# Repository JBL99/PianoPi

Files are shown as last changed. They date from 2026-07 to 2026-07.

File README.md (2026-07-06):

# PianoPi

PianoPi is a Raspberry Pi 5 MIDI player for a solenoid-driven piano/keyboard rig.
It plays MIDI files through physical solenoids, mirrors notes to an LED strip, can play speaker audio through FluidSynth, and includes a Tkinter control UI plus a local web control page.

## Features

- Tkinter touchscreen-friendly MIDI player
- Physical solenoid playback through PCA9685 boards
- Sustain pedal control through MIDI CC64
- LED strip note mirroring and idle effects
- FluidSynth speaker playback
- Instrument/track mixer
- Keyboard recording support when `real_piano` is false
- Local web control page on port 8000 by default
- CSV play history log

## Hardware this was built for

- Raspberry Pi 5, 64-bit Raspberry Pi OS
- PCA9685 PWM boards for solenoids
- `pi5neo` LED strip control
- FluidSynth with a General MIDI soundfont
- Optional USB MIDI keyboard for keyboard test mode

## Install system packages

```
sudo apt update
sudo apt install -y python3-pip python3-tk fluidsynth fluid-soundfont-gm alsa-utils git
```

For the local web UI and visualizer, you may also want Chromium installed:

```
sudo apt install -y chromium-browser
```

## Install Python dependencies

```
python3 -m pip install -r requirements.txt
```

On the Pi with hardware attached:

```
python3 -m pip install -r requirements-pi.txt
```

## Configure

Copy the example config:

```
cp player_config.example.json player_config.json
```

Edit `player_config.json`:

```json
{
  "midi_dir": "/home/pi5/Desktop/midiMusicFiles",
  "sound_font": "/usr/share/sounds/sf2/FluidR3_GM.sf2",
  "real_piano": false,
  "touchscreen_osk_auto_show": true,
  "web_host": "0.0.0.0",
  "web_port": 8000
}
```

`real_piano` controls which hardware mode/profile is used:

- `false`: keyboard test rig mode, with recording buttons visible
- `true`: real acoustic piano mode

You can also override a few settings with environment variables:

```
PIANOPI_MIDI_DIR=/path/to/midi PIANOPI_WEB_HOST=127.0.0.1 python3 PianoPi.py
```

## Run

```
python3 PianoPi.py
```

## Web control page

By default the web server binds to:

```text
0.0.0.0:8000
```

That means it listens on all network interfaces so another device on the same trusted local network can open:

http://<your-pi-ip>:8000/
```

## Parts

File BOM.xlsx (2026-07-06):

Description | Name | Qty | Cost | Shipping/Tax | Total | Link
JF-1039B Solenoids | Pack of 100: JF-1039B DC 12V 25N 400mA 10mm Push Pull Linear Actuator Electromagnet Solenoid | 1 | $338.01 | $123.00 | $461.01 | https://www.alibaba.com/product-detail/JF-1039B-DC-12V-25N-400mA_1601296981729.html
4K touch screen monitor | WCKUN 4K Portable Touch Monitor, 15.6" inch 3840 * 2160 UHD w/USB-C HDMI Laptop Monitor, 2000:1 100% RGB IPS ，Aluminum Alloy Shell,10-Point Touch，Dual Speaker, HDR, for Home, Work | 1 | $188.99 |  | $188.99 | https://www.amazon.com/dp/B0DP8NKR5W
Plc driver boards, pnp input 3.3 - 5v, pnp output, 16 channel | 4-16CH 3.3V 5V 12V 24V PNP-NPN Digital Logic Converter 5A MOS Solid State Relay PLC Signal Amplifier Board for Motor Relay | 6 | $21.15 |  | $126.90 | https://www.aliexpress.us/item/3256807238669489.html
Raspberry Pi 8gb | Raspberry Pi 5 8GB RAM Board | 1 | $89.99 | $18.73 | $108.72 | https://www.centralcomputer.com/raspberry-pi-5-8gb-ram-board.html
80/20 Aluminum Extrusion 2020 | Pack of 10: Aluminum Profile Extrusion 2020 1220mm 10PCS T Slot Black European Standard Anodized CNC Aluminum Profile 10 Sets connectors 50PCS Nuts 1PC Spanner for DIY 3D Printer | 1 | $83.39 | $0.00 | $83.39 | https://www.amazon.com/dp/B0CCJ7HBX9
Filament | PLA | 1.1kg*10 Rolls / Black*10 | 0.5 | $89.99 | $0.00 | $44.99 | https://jayo3d.com/products/special-offer-jayo-1-1kg-5-10-rolls-collection-pla-pla-matte-high-speed-matte-petg-3d-printing-filament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
Sustain Pedal Solenoid | Heschen Solenoid Electromagnet, HS-1578B, DC12V 20mm Stroke, Force 50N, Push Pull Type, Open Frame, Linear Motion | 1 | $35.99 |  | $35.99 | https://www.amazon.com/dp/B09T35Z4QR
430 Watt computer power supply | CORSAIR CX series CX430 430W ATX12V v2.3 80 PLUS BRONZE Certified Active PFC Power Supply | 1 | $35.99 | $0.00 | $35.99 | Already had from 2015
256gb nvme SSD | OEM Hyn PVC10 256GB M.2 PCI-e GEN 4X4 NVME SSD Internal Solid State Drive 30mm 2230 Form Factor M Key Steam Deck | 1 | $33.99 |  | $33.99 | https://www.amazon.com/dp/B0FNP68QYR
LED RGB addressable light strip | BTF-LIGHTING FCOB COB WS2811(WS2812B) IC RGB 180LED/m 540IC LED Strip DC5V 9.8FT Individual Addressable Flexible High Density Uniform Light Dream Chasing Color 10mm Width(NO Adapter or Controller) | 1 | $32.99 | $0.00 | $32.99 | https://www.amazon.com/dp/B0D62NN4PL
Screw terminal ground bars | 2 Pack: 2x12 Position Terminal Block Distribution Module Breakout Board for AC DC 15 Amp | 3 | $9.99 | $0.00 | $29.97 | https://www.amazon.com/dp/B0GMHB5VTM
T-Track Nuts | T-Track Nuts Kit, M3 M4 M5 M6 2020 3030 Series for Aluminum Extrusion, Hex Socket Bolts & T-Sliding Nuts | 5 | $4.56 |  | $22.80 | https://www.aliexpress.us/item/3256808316984904.html
Screws to attach solenoids to 3D print | 10-200pcs G10.9 Black Carbon Steel DIN7991 Hex Socket Countersunk ISO7380 Round Allen Hexagon Socket Screw M2 M2.5 M3 M4 M5 M6M8 Carbon (DIN7991), M4(50pcs), 8mm | 5 | $4.23 |  | $21.15 | https://www.aliexpress.us/item/3256807130556980.html
Signal wire | 22 AWG Stranded Wire Spool 25ft Each 6 Colors Flexible 22 Gauge Silicone Hook up Wire Kit Electrical Tinned Copper Wire | 1 | $19.99 |  | $19.99 | https://www.amazon.com/dp/B089D29FHC?th=1
Power wire | 20 awg Silicone Electrical Wire 2 Conductor Parallel Wire line 200ft [Black 100ft Red 100ft] 20 Gauge Soft and Flexible Hook Up Oxygen Free Stranded Tinned Copper Wire | 1 | $18.98 |  | $18.98 | https://www.amazon.com/dp/B07K9JKXM9
I2C boards 5 qty | 1-5pcs PCA9685 16 Channel 12-bit PWM Servo motor Driver I2C Module Robot | 1 | $16.43 |  | $16.43 | https://www.aliexpress.us/item/3256805483968774.html
12V to Rasberry Pi PD Hat | Yahboom PD Power Expansion Board for Raspberry Pi5 8GB Power Board with Jetson/Raspberry Pi5/RDK Series for Portable Power Supply | 1 | $15.99 | $0.00 | $15.99 | https://www.amazon.com/dp/B0D3XMLMGW
Lever Nuts 75 pcs | 10-75 Pcs Orange Universal Type Quick Plug-in Terminals,Electrical Equipment Connectors,Wire Connector Terminals,250V/32A | 2 | $7.97 | $0.00 | $15.94 | https://www.aliexpress.us/item/3256806776748267.html
Plc driver boards, pnp input 3.3 - 5v, pnp output, 8 channel | 4-16CH 3.3V 5V 12V 24V PNP-NPN Digital Logic Converter 5A MOS Solid State Relay PLC Signal Amplifier Board for Motor Relay | 1 | $15.31 |  | $15.31 | https://www.aliexpress.us/item/3256807238669489.html
Raspberry Pi nvme hat | Geekworm X1002 PCIe to M.2 2280 NVMe SSD Bottom for Raspberry Pi 5 | 1 | $12.76 |  | $12.76 | https://www.centralcomputer.com/geekworm-x1002-pcie-to-m-2-2280-nvme-ssd-bottom-for-raspberry-pi-5.html
6in right angle micro HDMI to HDMI cable | Duttek Right Angle HDMI to Micro HDMI Cable, Extreme Thin Micro HDMI to HDMI Adapter Cable for 1080P, 4K, UltraHD, 3D, Ethernet (6 inch/ 15cm) | 1 | $12.72 | $0.00 | $12.72 | https://www.amazon.com/dp/B08QFMMHB7
Dupont wires | Dupont Line 10cm/20CM/30CM Male to Male+Female to Male + Female to Female Jumper Wire Dupont Cable for arduino DIY KIT - 1set 30CM | 5 | $2.49 |  | $12.45 | https://www.aliexpress.us/item/3256806885766712.html
Dupont wires | Dupont Line 10cm/20CM/30CM Male to Male+Female to Male + Female to Female Jumper Wire Dupont Cable for arduino DIY KIT - 1set 20CM | 5 | $2.19 |  | $10.95 | https://www.aliexpress.us/item/3256806885766712.html
Dupont connectors | Taiss 600PCS Dupont Connector Kit - 2.54mm 1/2/3/4/5/6/7 Pin Housing Connector and Male/Female Crimp Pin, Jumper Wire Cable | 1 | $9.99 | $0.75 | $10.74 | https://www.amazon.com/dp/B0B11SX39B
Molex connectors to connect to power supply | SinLoon Computer Molex 4 Pin Power Supply Extension Cable, 8 Inch IDE Power to Floppy Drive Power Interface Cable. 5-Pack (4Pin) | 1 | $8.99 | $0.00 | $8.99 | https://www.amazon.com/dp/B09SYLNX8P
I2C Board to PLC board wires | 10PCS 2.54MM Dupont Line Male Female Double Headed 1P 2P 3P 4P 5P 6P 7P 8P 9P 10 Pin Dupont Jumper Cable Wire for PCB - 20cm, 4P, Male to Female | 3 | $2.93 |  | $8.79 | https://www.aliexpress.us/item/3256803571055717.html
Bumpers for inside solenoids | 5000PCS Dental Orthodontic Elastic Rubber Bands Latex Teeth Braces Ortho Tool Dentist Ligature Ring 2.5 3.5 4.5 5 6.5OZ Force - 3.5oz Chimpunk | 1 | $7.56 |  | $7.56 | https://www.aliexpress.us/item/3256806248407763.html
80/20 corner brackets | 20Sets Corner Bracket, 40Pcs Drop in T Nuts and Hex Screw Bolt for Slot 6mm 2020 Series Aluminum Extrusion Profile Accessories | 1 | $7.18 |  | $7.18 | https://www.aliexpress.us/item/3256807163540541.html
24 pin Power Supply Extension cable | StarTech.com 8in 24 Pin ATX 2.01 Power Extension Cable - Power extension cable - 24 pin ATX (M) to 24 pin ATX (F) - 7.9 in - ATX24POWEXT | 1 | $6.25 | $0.00 | $6.25 | https://www.amazon.com/dp/B000FL60AI
Dupont extension wires - for daisy chaining I2C boards | 10PCS 2.54MM Dupont Line Male Female Double Headed 1P 2P 3P 4P 5P 6P 7P 8P 9P 10 Pin Dupont Jumper Cable Wire for PCB | 1 | $6.15 |  | $6.15 | https://www.aliexpress.us/item/3256803571055717.html
50V 57µF capacitor | 50V 57µF capacitor | 1 | $5.99 |  | $5.99 | https://www.amazon.com/B0F8C2ST9B
10 PCS M4 screws 30mm long | DIN912 M1.6 M2 M2.5 M3 M4 M5 M6 M8 Black 304 Stainless Steel Hexagon Hex Socket Head Cap Allen Bolt Screw Length=3-100mm | 2 | $2.70 | $0.00 | $5.40 | https://www.aliexpress.us/item/3256801599375629.html
6 pack MOSFET Trigger switch | 6 PCS Dual High-Power MOSFET Trigger Switch Drive Module, Upgrade 0-20KHz PWM Adjustment Electronic Switch Control Board Motor Speed Controller, Lamp Brightness Control, DC 5V-36V 400W, 15A (Max 30A) | 1 | $5.29 |  | $5.29 | https://www.amazon.com/dp/B0FMJH3DML
Raspberry Pi 5 Cooler | Raspberry Pi 5 Active Cooler Aluminum Heatsink PWM Speed Adjustable Fan Black Silver Blue Cooling Radiator for RPI 5 Pi5 | 1 | $4.39 | $0.00 | $4.39 | https://www.aliexpress.us/item/3256807290493635.html
10 PCS M4 screws 14mm long | DIN912 M1.6 M2 M2.5 M3 M4 M5 M6 M8 Black 304 Stainless Steel Hexagon Hex Socket Head Cap Allen Bolt Screw Length=3-100mm | 2 | $1.99 | $0.00 | $3.98 | https://www.aliexpress.us/item/3256801599375629.html
10 PCS M4 screws 12mm long | DIN912 M1.6 M2 M2.5 M3 M4 M5 M6 M8 Black 304 Stainless Steel Hexagon Hex Socket Head Cap Allen Bolt Screw Length=3-100mm | 2 | $1.87 | $0.00 | $3.74 | https://www.aliexpress.us/item/3256801599375629.html
USB C pigtail for monitor power | Pack of 5: 90 Degree USB C 2 Pin Bare Wire Open End Power Cord, 2 Pin Pigtail to Type C Male DIY Cable 5V/2A, for Replacement or Repair | 1 | $3.08 | $0.12 | $3.20 | https://www.aliexpress.us/item/3256809526057985.html
0.5m USB A to USB C 3.2 Gen2 cable for Raspberry Pi to monitor | Hannord USB3.2 10Gbps USB A to USB C 3.2 Gen2 Type-C Cable Data Transfer 3A 60W QC 3.0 Fast Charging for iphone Macbook SSD | 1 | $2.99 |  | $2.99 | https://www.aliexpress.us/item/3256809395920156.html
I2C boards 1 qty | 1-5pcs PCA9685 16 Channel 12-bit PWM Servo motor Driver I2C Module Robot | 1 | $2.78 |  | $2.78 | https://www.aliexpress.us/item/3256805483968774.html
CPU Power supply breakout cable | 8 pin ATX 12V CPU EPS P4 Power Extension Cable 8pin 18cm Extend Cable Wire 18AWG Power Supply for Bitcoin Miner Mining Machine | 1 | $1.59 |  | $1.59 | https://www.aliexpress.us/item/3256805256834183.html
GPU Power supply breakout cable | 8Pin Male To Dual 4Pin Male Video Card Power Cord 8 Pin PCI Express To Dual 4 Pin Molex Graphics Card Power Cable | 1 | $1.39 |  | $1.39 | https://www.aliexpress.us/item/3256806427492521.html
3D printer | Bambu Lab A1 Combo 3D Printer | 0 | $379.99 | $0.00 | $0.00 | https://www.microcenter.com/product/675479/bambu-lab-a1-combo-3d-printer
Optional: Piano Keyboard for portable setup | Alesis 88 Key Keyboard Piano with 480 Sounds, Speakers, USB MIDI, Carry-Bag, Stand, Headphones, Pedal and Piano Lessons for Beginners | 0 | $189.00 | $0.00 | $0.00 | https://www.amazon.com/dp/B0CLVRL7YW
Total |  |  |  |  | $1474.81

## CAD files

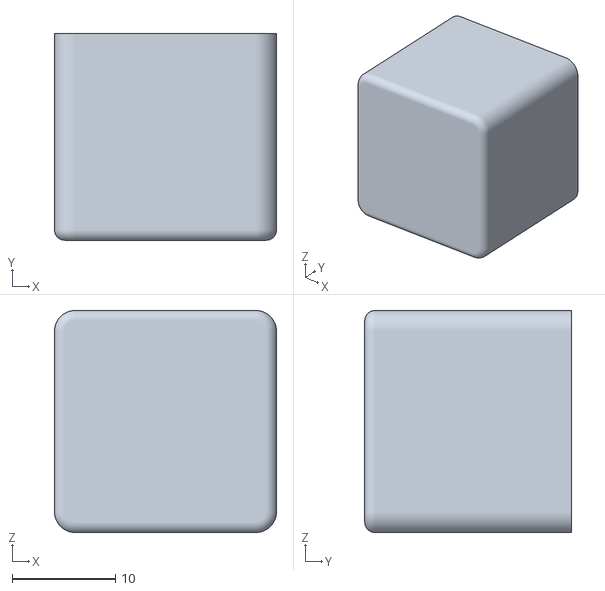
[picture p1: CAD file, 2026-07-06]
CAD/Aluminum Extrusion Cap.stl
21.5 x 20.0 x 21.5

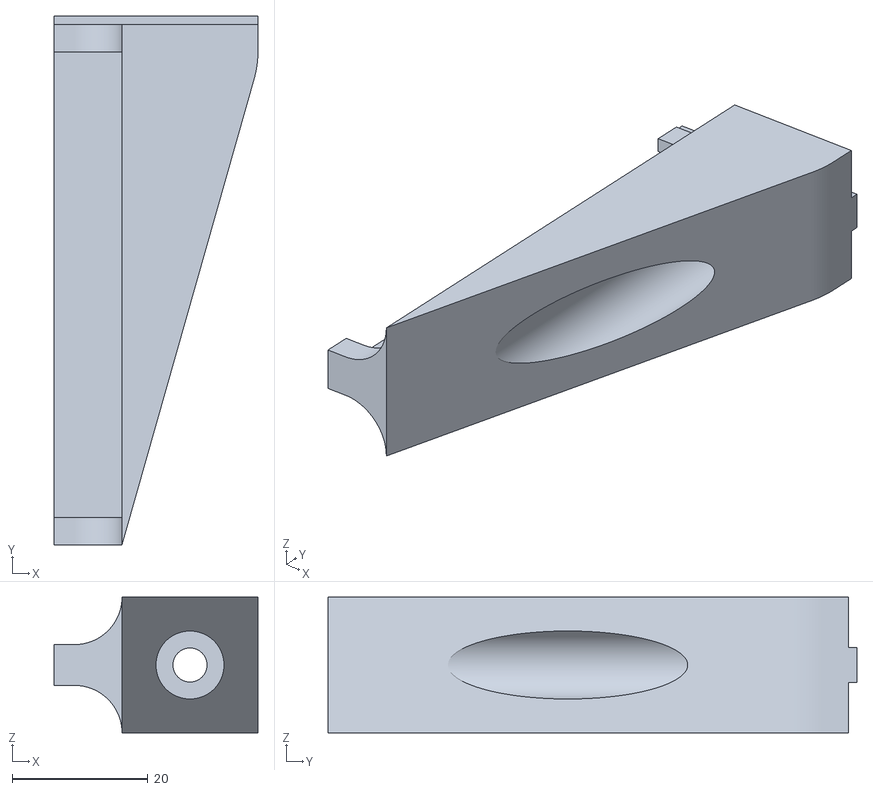
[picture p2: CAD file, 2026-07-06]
CAD/PLC Board Holder Right.stl
30.0 x 77.8 x 20.0

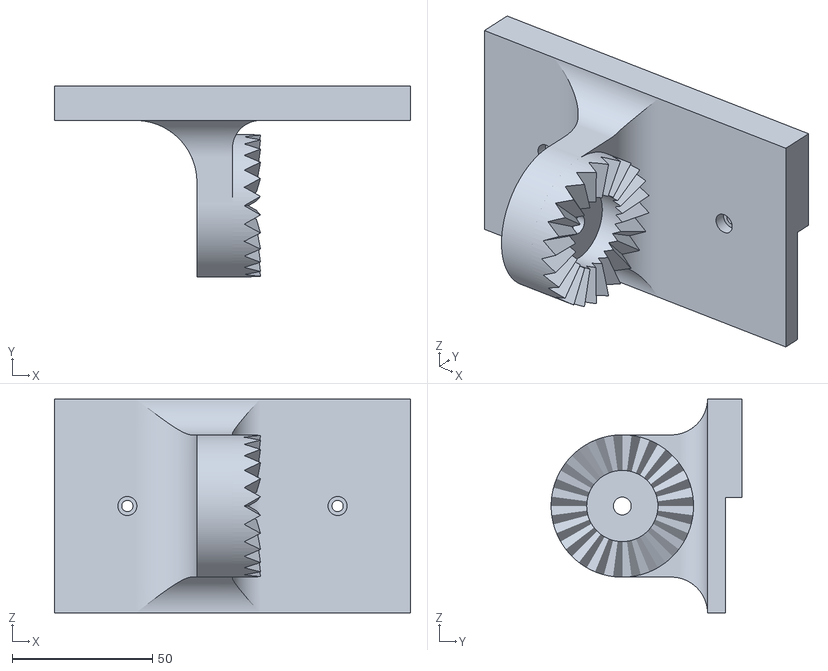
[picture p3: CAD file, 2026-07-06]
CAD/Monitor back bracket wich calced hirth coupling.stl
127.0 x 68.1 x 76.2

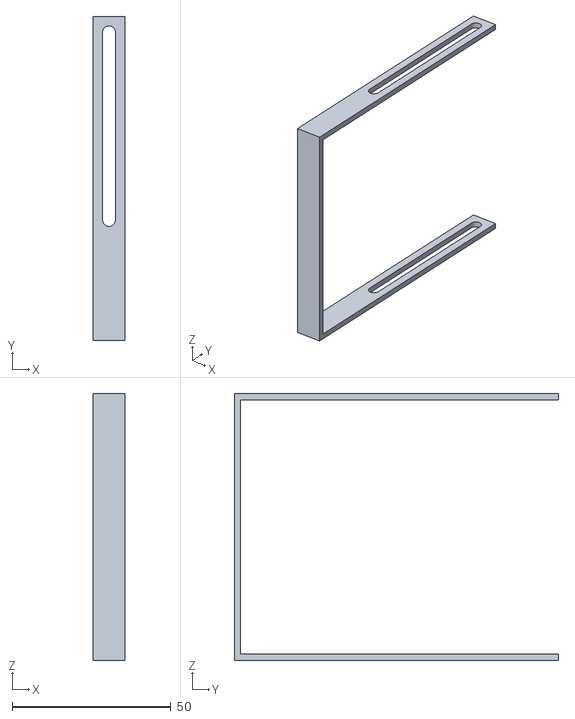
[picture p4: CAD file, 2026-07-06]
CAD/pedal solenoid braketV2 bottom.stl
10.0 x 102.0 x 84.0

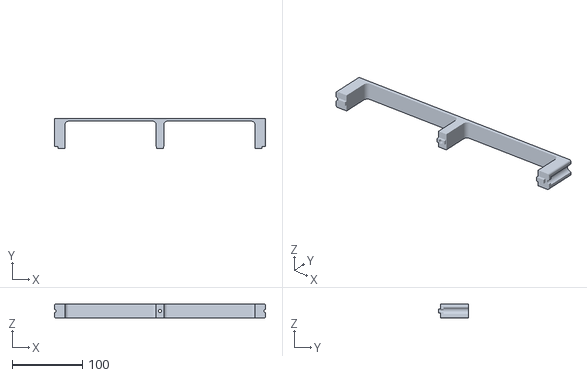
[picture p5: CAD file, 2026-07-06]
CAD/LED strip extender.stl
300.0 x 43.0 x 20.0

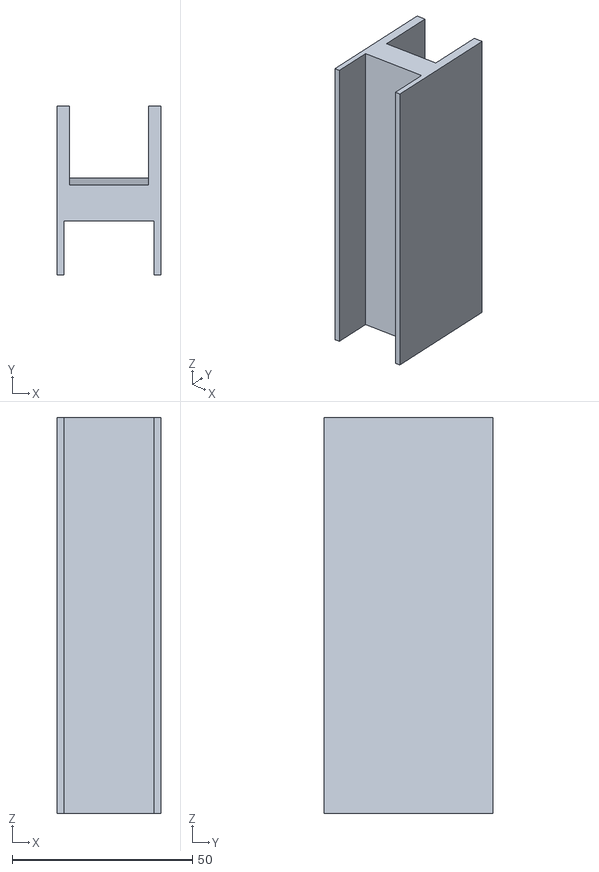
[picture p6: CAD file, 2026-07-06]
CAD/Piano Keyboard Stand.stl
29.0 x 47.0 x 110.0

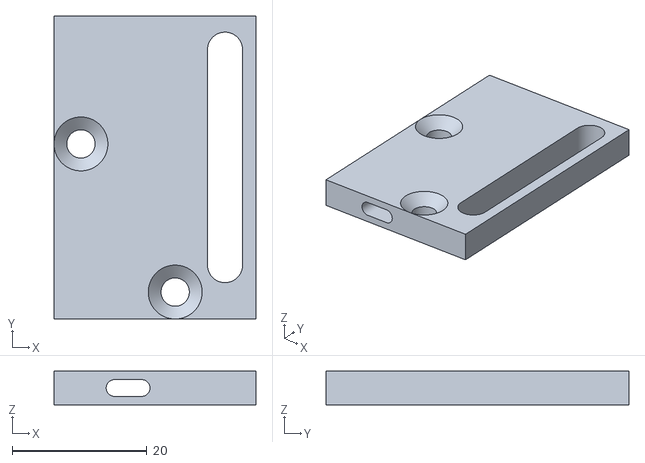
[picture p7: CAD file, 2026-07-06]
CAD/JF-1039B Black Key Bracket only 1.stl
30.0 x 45.0 x 5.00

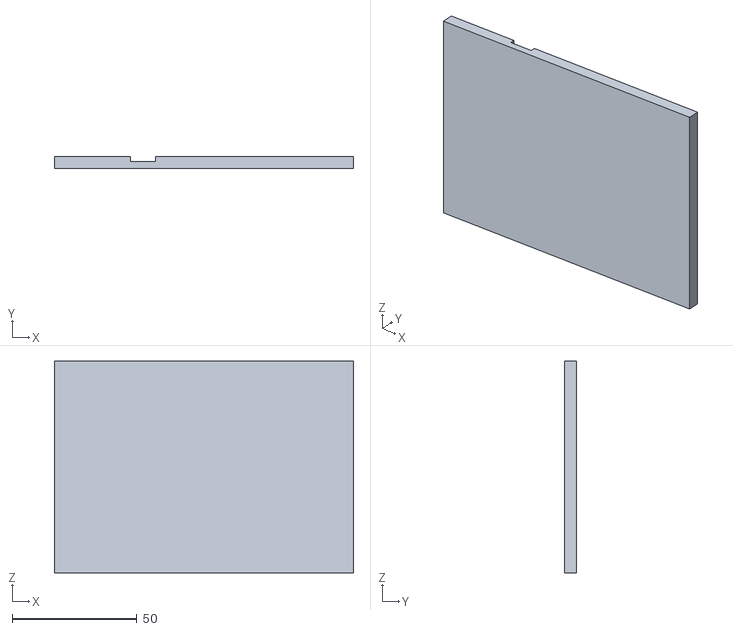
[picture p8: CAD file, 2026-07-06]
CAD/Pedal Base.stl
120.0 x 5.00 x 85.0

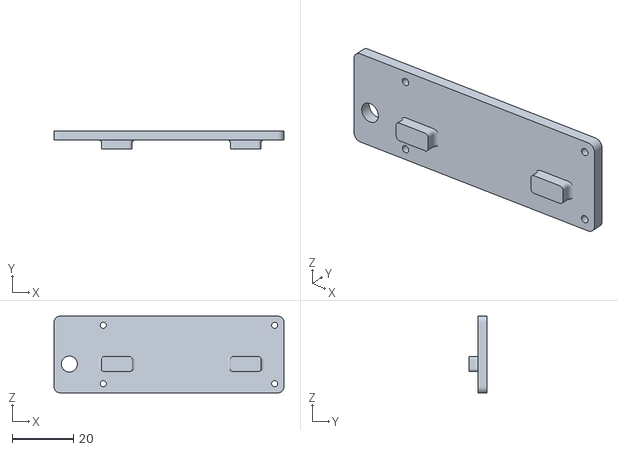
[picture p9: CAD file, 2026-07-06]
CAD/i2c board back.stl
75.0 x 6.00 x 25.0

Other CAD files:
CAD/PLC Board Holder Left.stl
